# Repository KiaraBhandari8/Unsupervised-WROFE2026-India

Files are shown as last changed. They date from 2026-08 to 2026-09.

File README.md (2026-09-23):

# Unsupervised-WROFE2026-India

Official repository of Team Unsupervised for the World Robot Olympiad Future Engineers 2026. This project documents the design, development, and implementation of our autonomous vehicle, integrating computer vision, embedded systems, and real-time navigation algorithms to solve the Future Engineers challenge.

## Table of Contents

- [Unsupervised-WROFE2026-India](#unsupervised-wrofe2026-india)
  - [Table of Contents](#table-of-contents)
  - [Team](#team)
  - [About the Challenge](#about-the-challenge)
  - [Performance Videos](#performance-videos)
    - [Challenge 1](#challenge-1)
    - [Challenge 2](#challenge-2)
  - [List of Components](#list-of-components)
  - [Robot Pictures](#robot-pictures)
  - [Mobility Management](#mobility-management)
    - [Controlling the Motor](#controlling-the-motor)
    - [Robot Dimensions](#robot-dimensions)
    - [Drivetrain Torque Calculation](#drivetrain-torque-calculation)
  - [Building Instructions](#building-instructions)
  - [Power and Sense Management](#power-and-sense-management)
    - [Power Distribution](#main--power-supply)
    - [Robot Dimensions](#robot-dimensions)
    - [Controlling the Motors](#controlling-the-motors)
  - [Building Instructions](#building-instructions)
  - [Power & Sense Management](#power--sense-management)
    - [Hardware Architecture](#hardware-architecture)
      - [Current Stabilisation](#current-stabilisation)
  - [Obstacle Management](#obstacle-management)
    - [Vision Methods and Decision Making](#vision-methods-and-decision-making)
    - [1) Image Pipeline (Inputs Used by Algorithms)](#1-image-pipeline-inputs-used-by-algorithms)
    - [MATLAB-Based Obstacle Detection and Colour Segmentation](#matlab-based-obstacle-detection-and-colour-segmentation)
      - [HSV-Based Colour Segmentation](#hsv-based-colour-segmentation)
      - [Generation of Colour Masks](#generation-of-colour-masks)
      - [Obstacle Selection](#obstacle-selection)
      - [Engineering Significance](#engineering-significance)
    - [2) Wall Following Calculations](#2-wall-following-calculations)
    - [3) Obstacle Handling Calculations](#3-obstacle-handling-calculations)
    - [4) Corner Detection](#4-corner-detection)
    - [5) Crash Detection](#5-crash-detection)
    - [6) Arbitration: Choosing the Action](#6-arbitration-choosing-the-action)
    - [7) Tuning Notes](#7-tuning-notes)
    - [Block Diagrams](#block-diagrams)
      - [Open Round Block Diagrams](#open-round-block-diagrams)
      - [Obstacle Round Diagrams](#obstacle-round-diagrams)
      - [Corner Logic Open Round](#corner-logic-open-round)
      - [Corner Logic Obstacle Round](#corner-logic-obstacle-round)
    - [Possible Improvements](#possible-improvements)
    - [Thank You](#thank-you)

## Team
wro
 <br>

| Name | Profile | Role |
| --- | --- | --- |
| Kiara Bhandari | Grade 10 @ Oberoi International School | Team Member |
| Shubh Gupta | Grade 10 @ Chatrabhuj Narsee School | Team Member |
| Dhanak Seth | Grade 8 @ Vibgyor High School | Team Member |
| Vinay Ummadi | Mentor @ MakerWorks Lab | Team Mentor |

## About the Challenge

The World Robot Olympiad (WRO) is an international robotics competition that encourages students to develop problem-solving, programming, and engineering skills. The Future Engineers category is designed for students aged 14–22 years and focuses on autonomous driving. The challenge simulates real-world traffic conditions and requires teams to design and program a fully autonomous robot car.

The challenge requires students to construct an autonomous robot which will undergo 2 rounds. First, an open round challenge where the robot would need to complete 3 rounds around the arena within the time limit of 3 minutes (180 seconds). The second round, which is the obstacle round consists of navigating through red and green pillars, where the robot would move from the left of the green pillar and from right of the red pillar. The robot should once again, not exceed a time limit of 3 minutes.

## Performance Videos
### Challenge 1
[Open Challenge Video 1 - Practice before Nationals on Youtube](https://youtu.be/0ms9o5Httb8?si=1wx8qC69ZG0JPVR6)

### Challenge 2
[Obstacle Round Video 1 - Practice before Nationals on Youtube](https://youtu.be/hUuTf3fS2V0?si=C6_U4KdSrS-R3kdz) <br>
[Obstacle Round Video 2 - Practice before Nationals on Youtube](https://youtu.be/6QX_Y3WPMX4?si=ZPCf-lAfKMT5tgFE) <br>
[Obstacle Round Video 3 - Practice before APAC on Youtube](https://youtu.be/BjEGykfpRfE)

## Matlab Video
[Youtube Video: Explanation On How We Used Matlab](https://youtu.be/cSldkeClAug?si=Nf5bUmlcxWWf90j0)
[Obstacle Round Video 2 - Practice before Internationals on Youtube](https://youtu.be/6QX_Y3WPMX4?si=ZPCf-lAfKMT5tgFE)

## List of Components

| Name of Component | Quantity | Picture |
| ---- | ---- | ---- |
| Raspberry Pi 5 (Cooling Fan + SD Card) | 1 |  |
| Raspberry Pi Camera Module 3 Wide | 1 |  |
| ESP32 Development Board | 1 |  |
| YDLidar T-Mini Plus LiDAR | 1 |  |
| PCA9685 16-Channel PWM Servo Driver | 1 |  |
| TB6612FNG Dual Motor Driver | 1 |  |
| GY-87 10-DOF Multi-Sensor IMU Module | 1 |  |
| Silicon Labs CP2102 USB-to-UART Bridge | 1 |  |
| HC-SR04 Ultrasonic Sensor | 1 |  |
| MG996 Servo Motor | 1 |  |
| 12V DC 600 RPM Encoder Motor | 1 | 617ee66bbc025d72da6e6f25634cf3e0 image 1066x800 |
| LiPo 3s 11.1v 2200 mAh Battery | 1 |  |
| LM2596 Step-Down (Buck) DC-DC Switching Voltage Regulator Integrated Circuit (ESP32) | 1 |  |
| XY-3606 DC-DC Step-Down Buck Converter Module (Raspberry Pi) | 1 |  |
| RC Car Rear Differential | 1 |  |
| N20 wheels | 4 |  |
| Lazy Susan Turntable Bearings | 1 |  | 

[Why we chose each component](mech/components) <br>
## Robot Pictures

WhatsApp Video 2026-08-18 at 6 07 50 PM

360° view

<br> <br>

| Front View | Left View | Top View |
| --- | --- | --- |
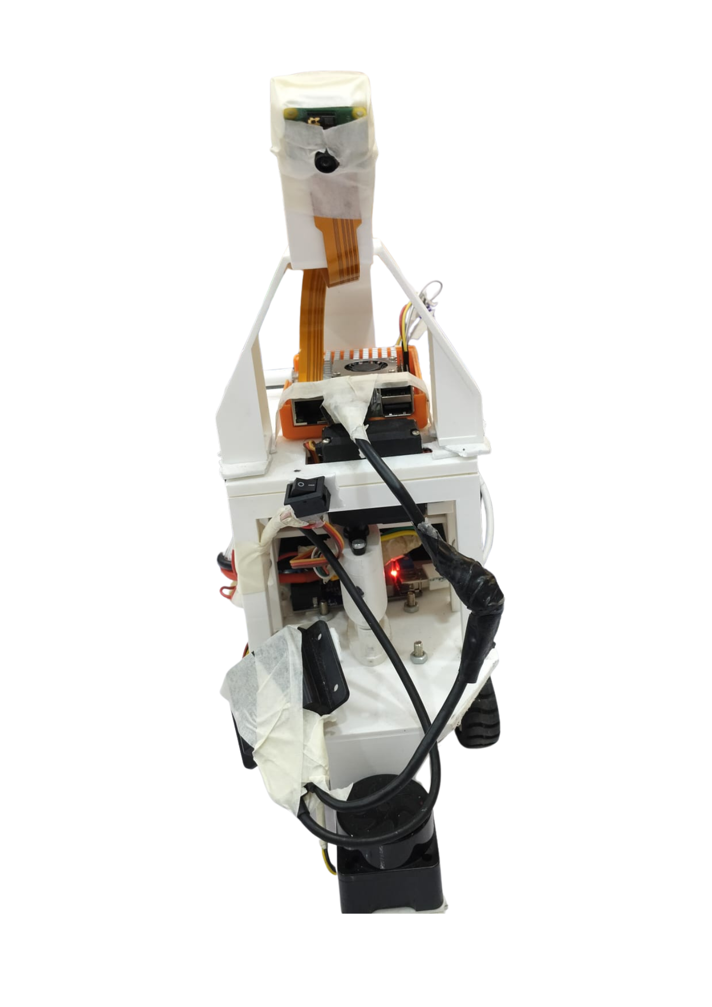
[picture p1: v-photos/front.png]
Front View
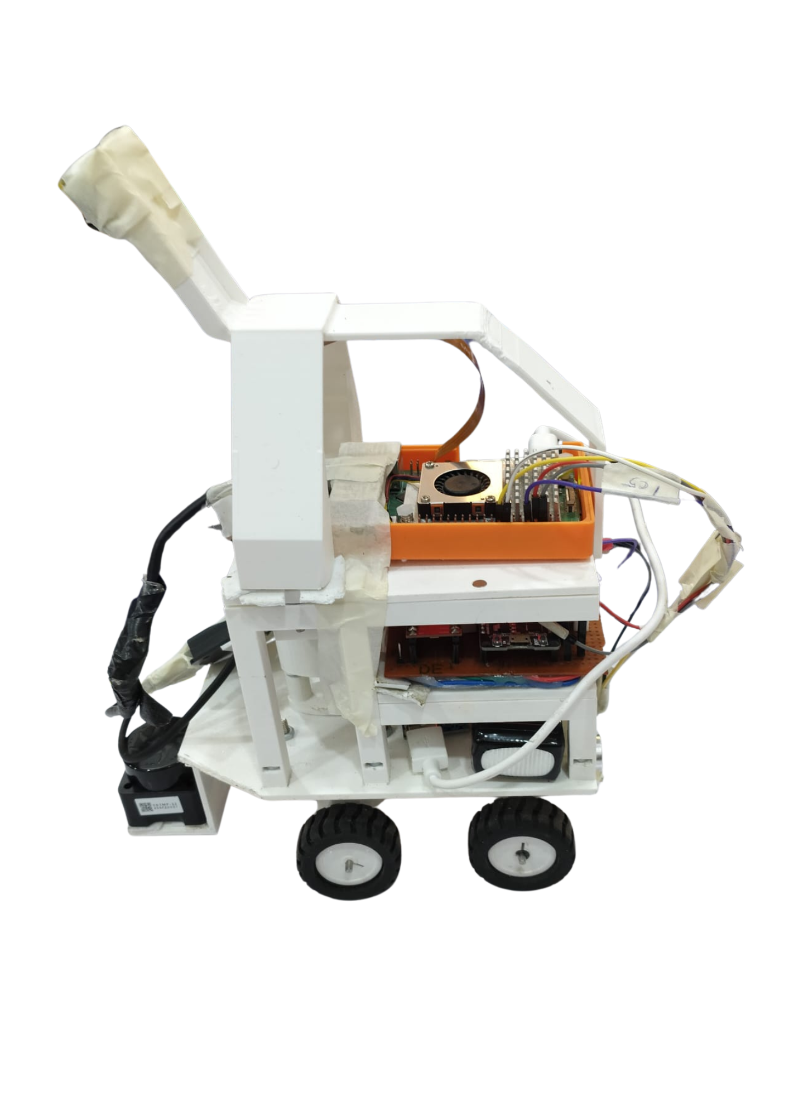
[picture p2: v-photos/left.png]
Left View
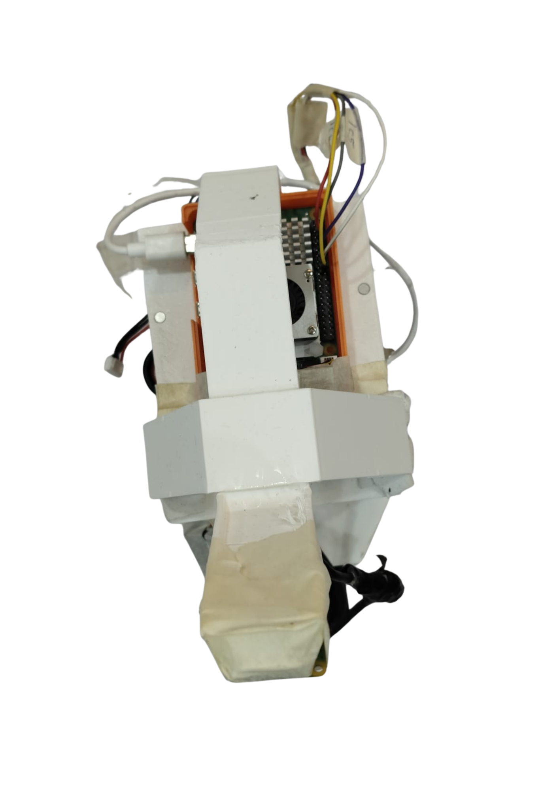
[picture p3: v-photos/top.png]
Top View
|  |  |  |

| Back View | Right View | Bottom View |
| --- | --- | --- |
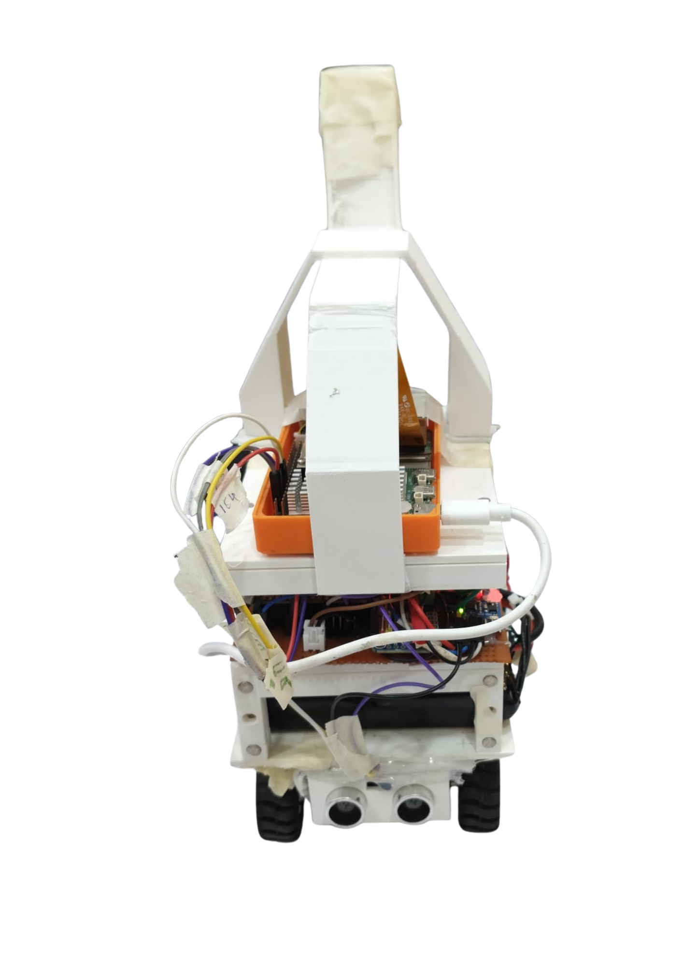
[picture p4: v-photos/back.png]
Back View
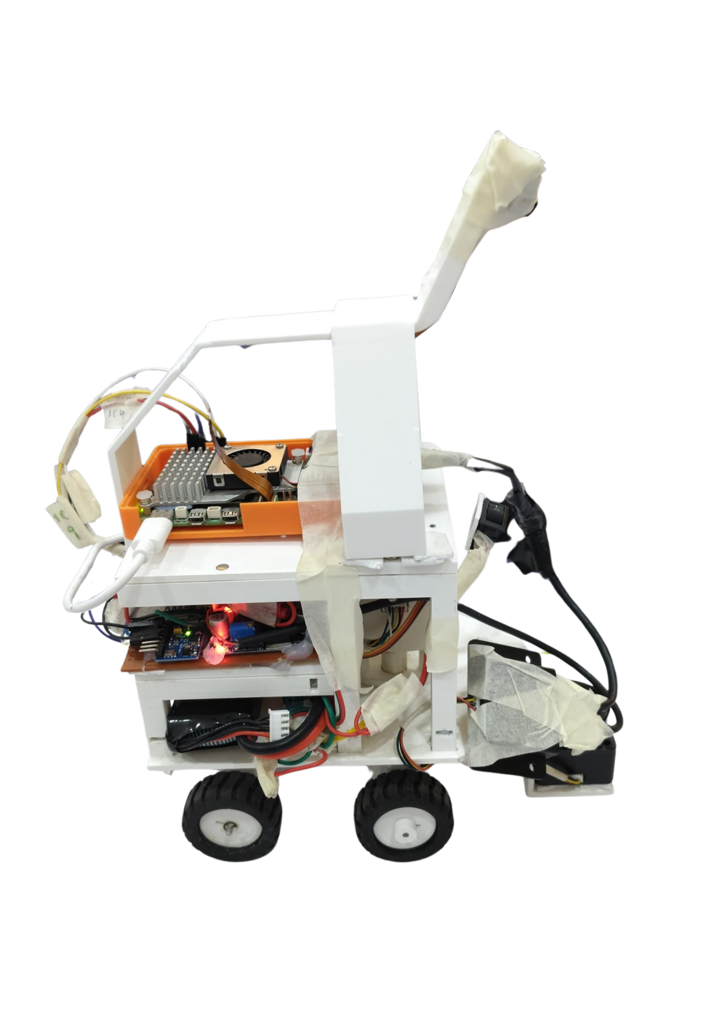
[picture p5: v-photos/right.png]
Right View
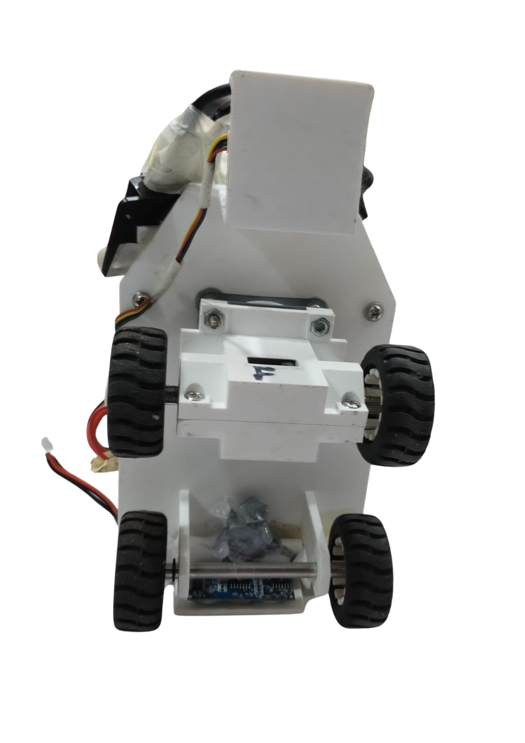
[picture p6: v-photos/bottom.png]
Bottom View
|  |  |  |

## Mobility Management

The robot uses a rear-wheel-drive system consisting of one 12V 600 RPM DC encoder motor connected to an RC car rear differential. The differential transfers the motors' motion to the rear wheels while allowing the wheels to rotate at different speeds during turns. Steering is provided by an MG996 servo motor connected to the front steering mechanism. The robot uses four N20 wheels, with the rear wheels being driven and the front wheels used for steering. A Lazy Susan turntable bearing supports the steering assembly.

WhatsApp Image 2026-08-18 at 6 07 51 PM

### Robot Dimensions

- **Dimensions:** **22 cm × 11 cm × 29 cm**  
**Length × Width × Height**

**Why We Chose These Dimensions:**

We chose the dimensions of **22 cm × 11 cm × 29 cm** to provide a balance between **stability, manoeuvrability, and component placement**. The 50 cm length provides enough space to accommodate the drivetrain, battery, electronics, and sensors while maintaining a compact overall design. The 29.5 cm width provides sufficient stability during movement and turning without making the robot unnecessarily wide. The 22 cm height keeps the robot's centre of mass relatively low while providing enough clearance for mounting the camera, LiDAR, and other electronic components. These dimensions also allow the robot to remain compact enough for efficient navigation around the track.

- **Custom Mounts**: Holders for servo, differential gear, camera, and LiDAR and more. <br> [CAD Designs](mech)

- **Differential Gear**: The differential  provides smoother and more mechanically appropriate turning behaviour than directly forcing both wheels to rotate at the same speed. <br> [Why We Chose Differential Gears](mech/components)

### Controlling the Motors

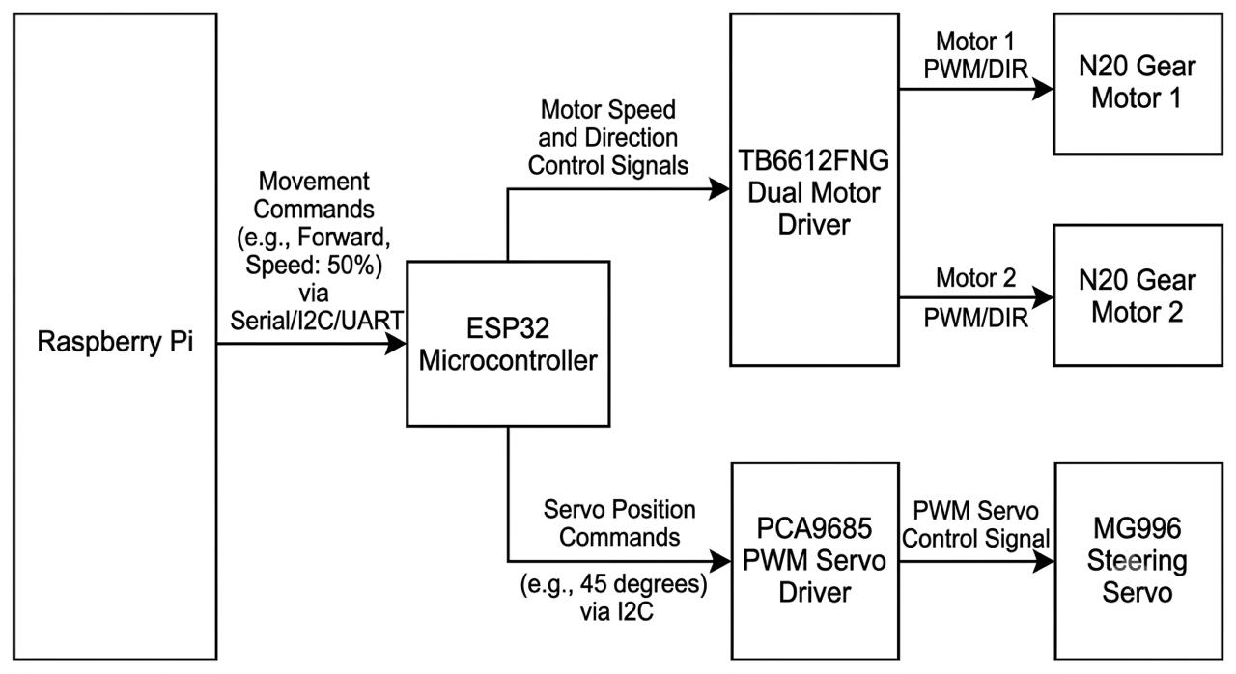
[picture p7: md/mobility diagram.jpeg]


The DC motor is controlled by the ESP32 through the TB6612FNG dual motor driver. The Raspberry Pi sends movement commands to the ESP32, which controls the motors according to the required speed and direction. The MG996 steering servo is controlled by the ESP32 through the PCA9685 PWM servo driver.

This code showcases our navigation manoeuvre. You can go through this to get a better understanding. [Click here for navigation code](codes/aug15_1/nav_process.py)

### Drivetrain Torque Calculation

[Click here to view the drivetrain torque calculation](docs/drivetrain-torque-calculation.md)

-------------------------------------------------------
## Building Instructions
- **Parts list** <br>
  Make sure you have all components ready before starting: 3D-printed parts, motors, drivers, electronics, screws, sensors and connectors. A complete detailed table with quantities, sources, link, prices and usage is included below for reference.<br>
[Click here to open the parts list](mech/components)

- **3D Printing Parts**<br>
  Using any 3D printer, start by 3D printing the necessary parts for the assembly. We used a Prusa Core 1. Every part needed has a STL file which you can use with any printer. If you're adventurous and want to modify a part, open the .STL file in your favorite CAD software. If you're unsure of what part you're printing, make sure to open the PNG file which contains a picture of the part.<br>
[Click here to open the .STL files](mech)

- **Custom PCB**<br>
  Fabricate the board using the Gerber files located in the project repository. Carefully solder all components onto the PCB, including power regulators, motor drivers, and pin headers. Before connecting battery power, perform a continuity test with a multimeter across the power and ground rails to ensure there are no short circuits.<br>
[Click here to open the schematics](elec/schematic.PNG)

- **Assemble the Robot**<br>
  Mechanically assembling the robot is quite straight-forward. The tricky part comes with the electrical connections. Make sure you follow correctly the following electrical drawings.<br>
_Take notes, the drawings are quite small ! Make sure to download the PDF files to be able to zoom._ <br>
[Click here to open the electrical drawings](elec/schematic.PNG)

- **Sensor Setup (LiDAR & Pi Camera)** <br>
  Secure the Pi Camera and LiDAR module onto their designated 3D-printed chassis mounts. Connect the camera to the host board's CSI port using the ribbon cable, ensuring correct pin orientation. Wire the LiDAR module to the host via USB or serial interface. Run the hardware verification scripts to verify the camera stream and confirm that 360-degree scan data is streaming cleanly into memory.<br>

## Power and Sense Management

### 1. Main Power Supply

The robot is powered from a single 11.1 V, 3S LiPo battery. A main power switch is placed immediately after the battery's positive terminal, so that every downstream circuit — both buck converters and the raw motor rail — is gated by this one switch. 

From the switched 11.1 V rail, power is distributed along two separate paths. The raw 11.1 V supply is routed directly to the VM pins of the TB6612FNG motor driver, so the motor is driven at full battery voltage without regulation. The same rail also feeds the input of the first buck converter, from which all regulated voltages in the system are ultimately derived.

This separation is intentional. Motor drive current is comparatively high and electrically noisy, due to switching transients and back-EMF, and is therefore kept on an unregulated path rather than passed through a converter that would otherwise have to absorb that noise.

### 2. Buck Converter 1: XY3036 (11.1 V to 5 V, 5 A)

The XY3036 steps the 11.1 V battery rail down to 5 V at up to 5 A. Its primary load is the Raspberry Pi 5, supplied through its USB-C input. The Pi 5 has comparatively high current demands, particularly with a camera and a USB-connected LiDAR adapter attached, and its power management IC actively monitors the current capability advertised on USB-C; an insufficient supply results in throttling. A 5 A-rated converter feeding the USB-C port directly is intended to avoid this condition.

The 5 V/5 A output of the XY3036 also serves as the input to the second buck converter, so every other regulated rail in the system is derived from this same supply, stepped down once more.

### 3. Buck Converter 2: LM2596 (5 V to 5 V, 2 A)

The LM2596 takes its input from the XY3036's 5 V output and regulates it down to 5 V at up to 2 A. Although the nominal voltage is unchanged, this stage is not redundant: its function is to provide a second, independently regulated rail so that the Raspberry Pi's supply is not shared directly with the motor driver logic or the servo driver.

The Raspberry Pi remains on the XY3036's dedicated rail. The ESP32 DEVKITC, the logic supply (VCC) of the TB6612FNG, and, indirectly, the BN0085 gyroscope and PCA9685 servo driver are instead supplied from the LM2596 rail. The motor driver's logic side switches at high frequency, and the servo draws current in bursts during motion; if these loads shared a rail directly with the Pi, the resulting ripple could couple into the Pi's supply and produce intermittent faults that are difficult to diagnose during competition. A second regulation stage isolates these load transients from the Pi's supply rail.

### 4. Rail Distribution Summary

| Rail Source | Load | |
| --- | --- | --- |
| 11.1 V (unregulated) | Battery, via main switch | TB6612FNG motor driver (VM) |
| 5 V, 5 A | XY3036 | Raspberry Pi 5 (USB-C) |
| 5 V, 2 A | LM2596, from XY3036 output | ESP32 DEVKITC, TB6612FNG logic (VCC) |
| 3.3 V | ESP32 onboard regulator, from LM2596 rail | BN0085 gyroscope, PCA9685 servo driver logic |

The 3.3 V rail is not produced by a discrete third converter. It is generated by the ESP32 DEVKITC's own onboard regulator, which takes its input from the LM2596 rail. The supply path to the gyroscope therefore passes through four regulation stages: battery, XY3036, LM2596, and the ESP32's internal regulator.

The PCA9685 has a separate supply pin, V+, in addition to its logic VCC, used specifically for the servo output stage. Servo current draw during motion is significantly higher than the I2C logic current, and keeping this path distinct from the logic supply reduces the likelihood of that current draw appearing as noise on the I2C bus.

### 5. Power Distribution to Sensing Elements

Each sensing subsystem draws power along a distinct path, generally following the controller to which it is connected.

The N20 encoders use a four-wire connection: two signal lines (C1 and C2, for quadrature pulse counting) to ESP32 GPIO32 and GPIO33, and separate VCC and GND lines supplying the encoder's Hall-effect sensing circuitry independently of the motor's own power pins. This separation prevents switching noise on the motor supply from affecting the encoder signal lines.

The ultrasonic sensor is supplied from a 5 V rail local to the Raspberry Pi, with TRIG and ECHO connected to Pi GPIO17 and GPIO27 respectively; it operates entirely within the Pi's I/O and power domain.

The LiDAR unit is powered through its USB adapter. Its VCC, GND, SCL, and SDA lines are local to the LiDAR module, and communication with the Raspberry Pi is carried over a USB cable via a USB translator, which also supplies the module's 5 V through the same cable. Its power is therefore drawn from the Pi's own USB supply rather than from either buck converter directly.

The Pi Camera 5 is powered over the CSI ribbon cable directly from the Raspberry Pi board.

The BN0085 gyroscope operates on the 3.3 V rail described in Section 4, with SDA and SCL connected to the ESP32 for orientation data.

In general, peripherals physically and logically associated with the Raspberry Pi (camera, ultrasonic sensor, LiDAR) draw power through the Pi's own supply, while peripherals associated with the ESP32 (encoder signal circuitry, gyroscope, servo driver) draw power through the ESP32's 5 V and 3.3 V rails. Power and data paths for each subsystem are therefore kept within the same controller domain.

### 6. Common Ground

All regulators, integrated circuits, and sensors share a common ground reference. This includes the UART bridge between the Raspberry Pi and the ESP32, which explicitly specifies a shared ground line alongside its TX and RX connections (Pi Pin 8 to ESP32 RX2, Pi Pin 10 to ESP32 TX2). UART is a single-ended signaling scheme with no differential reference, so a common ground between the two devices is required for reliable communication, independent of the condition of either device's own supply rail.

### 7. Summary

The power architecture reflects three design decisions. Motor power is kept unregulated and isolated from all logic rails. The Raspberry Pi is supplied from a dedicated high-current converter that is not shared as a load by any other device. All comparatively noisy loads, including motor driver logic, the servo, and the IMU, are supplied from a second, independently regulated converter, isolating their transients from the Pi's supply.

#### Current Stabilisation

The robot uses DC-DC buck converters to regulate the voltage supplied to its electronic components. This prevents the higher battery voltage from being supplied directly to components that require lower operating voltages.

The regulated power system helps maintain stable operation of the Raspberry Pi, ESP32, sensors, and control electronics during operation.

### Hardware Architecture

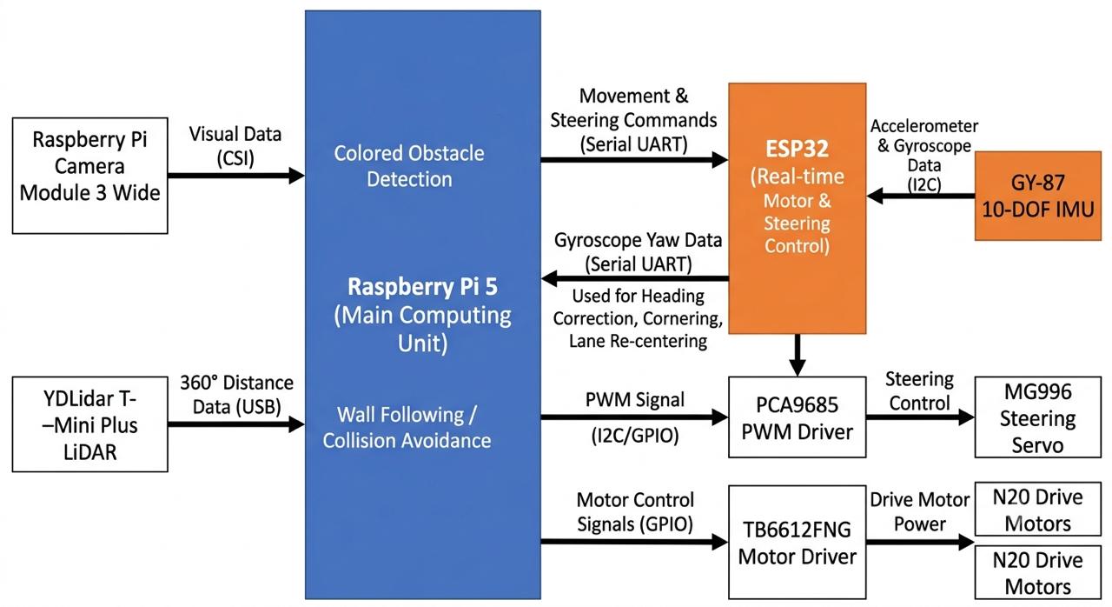
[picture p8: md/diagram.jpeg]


The Raspberry Pi 5 acts as the main computing unit and processes data from the Raspberry Pi Camera Module 3 Wide and YDLidar T-Mini Plus LiDAR. The Raspberry Pi communicates with the ESP32 through a serial connection to send movement and steering commands. <br> [Why We Chose the Pi 5](mech/components)

The ESP32 handles real-time motor and steering control and interfaces with the robot's sensors. The GY-87 10-DOF IMU provides accelerometer and gyroscope data to estimate the robot's orientation and heading. Gyroscope yaw data is streamed from the ESP32 to the Raspberry Pi and is used by the navigation software for heading correction, cornering, and lane re-centering after obstacle avoidance. <br> [Why We Chose the ESP32](mech/components)

The YDLidar T-Mini Plus provides distance measurements around the robot for wall following and collision avoidance, while the camera provides visual information for detecting and avoiding coloured obstacles. <br> [Why We Chose the YDLiDAR](mech/components)

The PCA9685 PWM driver controls the MG996 steering servo, while the TB6612FNG motor driver controls the DC motors. 

## Obstacle Management

The robot uses a combination of computer vision, LiDAR, and IMU data to detect obstacles and determine its path through the arena.

### Vision Methods and Decision Making

Untitled design

The Raspberry Pi Camera Module 3 Wide is used to identify the coloured obstacles in the arena. Image processing is used to detect red and green obstacles and determine their position relative to the robot.

The YDLidar T-Mini Plus provides distance measurements around the robot. These measurements are used for wall following, obstacle detection, and determining the available space around the robot.

The GY-87 IMU provides accelerometer and gyroscope data. Gyroscope yaw data is used by the navigation software for heading correction, cornering, and lane re-centering after obstacle avoidance.

The navigation system combines information from these sensors to determine the appropriate steering angle and motor speed. The Raspberry Pi processes the sensor data and sends movement commands to the ESP32, which controls the steering servo and drive motor. 

# Obstacle Detection, Processing, and Avoidance

## 1. System Overview

Two sensors split the job:

| Sensor | Role |
|---|---|
| Camera (RGB, HSV color analysis) | Figures out the **type** of obstacle — red pillar, green pillar, or none |
| LiDAR | Measures **distance** to walls and obstacles, spots corners, and handles wall-following and stop triggers |

In short: the camera tells the robot *what* it's looking at and which side to pass on; the LiDAR tells it *how close* things are and *when* to act. The driving logic combines both to decide on one maneuver per track section.

---

## 2. Detection Stage

### 2.1 Track Isolation (Track Segmentation)

Before checking for obstacle colors, the system figures out which part of the camera frame is actually the drivable mat, so background clutter or walls never get mistaken for an obstacle.

docuemntaiton1 <br> 

- Convert the frame from BGR to **HSV color space** and threshold the **L (lightness) channel** to separate bright mat pixels from dark background/obstacle pixels.
- Run a morphological **close** (dilate → erode) to bridge small gaps caused by colored tape lines, so tape doesn't split the mat into separate regions.
- Use `cv2.connectedComponentsWithStats` to find all bright regions, then keep only the one **touching the bottom row** of the frame — that's the track the robot is currently on. Discard everything else.
- This gives a binary **track mask** (255 = track, 0 = everything else). An obstacle sitting on the mat blocks the brightness underneath it, so it shows up as a dark "hole" inside the track region.
- Fill that hole in to get a **filled interior mask** — "everything inside the track boundary, obstacle or not." This is needed because the raw track mask would blank out the very obstacle the pipeline is trying to find; the filled version is what color detection actually gets restricted to.

### 2.2 Color-Based Pillar Detection

With the interior mask ready, the system looks for red and green pillars using HSV thresholding:

Screenshot 2026-09-19 at 6 23 32 PM <br>

- Convert BGR to **HSV**, since HSV separates color (hue) from lighting (saturation/value) much better than BGR.
- **Green mask:** one hue range (default 35–85) plus minimum saturation/value floors.
- **Red mask:** red wraps around the hue wheel at 0°/180°, so two hue ranges (default 0°–7° and 173°–180°) are combined with `cv2.bitwise_or`.
- Saturation/value floors are **tunable live** at runtime (thread-safe parameter store) to handle lighting changes at the venue without re-flashing code. Hue bounds stay mostly fixed since hue doesn't shift much with lighting — only their edges (where red/green fade into orange/yellow) are adjustable.
- Apply a **morphological close** (7×7 elliptical kernel) to each color mask first, to reconnect a single obstacle that glare or reflections split into separate blobs.
- **AND** both masks with the track interior mask from Section 2.1. This removes any pillar-colored object outside the track boundary at the pixel level, so it's never even offered to the contour detector.
- If a post-corner rejection zone is active (a short window after a corner maneuver where leftover motion or a partial-turn frame could cause false detections), also mask out a vertical strip on the relevant side.
- Detection is limited to a **Region of Interest (ROI)**: roughly the central 70% of frame width (15%–85%) and middle 76% of height (12%–88%). This avoids lens distortion and clutter at the extreme edges, while still leaving room for distant, small, high-in-frame obstacles to register at their true size.
- Run `cv2.findContours` separately on the red and green masks. Drop any contour under **900 px²** to filter out tape specks, reflections, or noise.
- If both colors have a surviving contour, pick the **larger** one, assuming the bigger blob is the nearer, currently-relevant obstacle.
- Output: a `logic_label` of `red_obstacle`, `obstacle` (green), or `none`.
- As a diagnostic aid: even if nothing clears the area filter, the largest unfiltered contour (either color) is still tracked and reported with its real area — this helps tell "obstacle present but too small/clipped" apart from "color threshold isn't catching it at all."

---

## 3. Processing Stage

There are two separate processing modes for two different purposes.

### 3.1 Continuous PD Steering Correction

Used for real-time, frame-by-frame pillar avoidance and for the standalone diagnostic tool:

Screenshot 2026-09-19 at 6 23 43 PM <br>

- **Target point:** each color aims for an x-coordinate at the ROI edge opposite the side it must pass on (green → right edge, red → left edge), so the correction steers toward the correct passing side, not just toward the obstacle.
- **Error:** horizontal pixel distance between the obstacle's detection point (bottom-center of its bounding box) and its target x-coordinate.
- **PD control law:**
  ```
  steering_angle = Kp * error + Kd * (error - previous_error)
  ```
  with `Kp = 0.45`, `Kd = 0.1`. The derivative term smooths out single noisy frames. `previous_error` is stored per color across frames so the derivative term has something to compare against.
- **Y-offset correction:** an extra term, `Y_OFFSET_GAIN * (obstacle_bottom_y - ROI_top_y)`, adds more steering push the closer the obstacle's bottom point is to the robot, applied in the direction of the x-error's sign. So correction strengthens as the robot approaches, instead of staying constant.
- **Fallback when nothing is detected:** switch to line-centering — compare black pixel area on the left vs. right half of the ROI (the track lines) and steer to balance them. If the frame is very dark overall (mean grayscale under 50), treat it as a wall/corner ahead and apply a fixed sharp turn instead.
- When no pillar is tracked in a frame, reset both colors' `previous_error` to zero, so a stale derivative doesn't cause a steering spike if a pillar reappears later.

### 3.2 Single-Shot Classification with Lap Memory

The competition run doesn't steer continuously around pillars — instead it takes **one classification read per checkpoint** via `read_obstacle()`:

Screenshot 2026-09-19 at 6 23 54 PM <br>

- **Lap 1:** every section is actively scouted — capture a frame, run it through the Section 2 pipeline, and store the result (`red` / `green` / `none`) in a section map keyed by `(direction, section, level)`. A section can hold up to three obstacle positions (L1/L2/L3), but only specific combos are valid (a single obstacle, or L1+L3 — never L1+L2 or L2+L3).
- **Later laps:** skip the camera for any section already scouted, and just recall the stored classification. This avoids risking a bad live read (motion blur, blocked view, lighting drift) for something that's already known and constant.
- If a scouting read got cut short (e.g. a safety timeout), `read_obstacle()` falls back to a live capture instead of trusting an incomplete record.

---

## 4. Avoidance Stage

Once a `logic_label` (live or recalled) is available, the robot runs a fixed, pre-defined maneuver rather than steering freely:

- **Green obstacle →** pass on the **right** (pillar stays on the robot's left).
- **Red obstacle →** pass on the **left** (pillar stays on the robot's right).
- **No obstacle →** take the default straight-through route.

Each maneuver typically pairs with LiDAR-driven **wall-following-and-stop** (Section 5): the robot advances under wall-follow PID until the LiDAR's front distance crosses a stop threshold (350 mm for both green and "none" at checkpoint L3), then the next scripted turn fires.

---

## 5. LiDAR's Role in Avoidance

While the camera identifies the obstacle, the LiDAR continuously provides the distance/geometry needed to execute the maneuver safely:

Screenshot 2026-09-19 at 6 24 36 PM <br>

- **Front distance:** average of valid LiDAR points within ±10° of straight ahead — the main trigger for "stop advancing, execute next turn."
- **Wall-parallel error:** PID input measuring how parallel the robot is to the wall it's following (left wall clockwise, right wall counter-clockwise, chosen dynamically from live shared state). Keeps a steady 500 mm standoff while passing a pillar.
- **Side-zone triggers:** points in the 50°–90° zone on each side are checked against a 200 mm threshold. 3+ such points trip a raw "obstruction on this side" flag — an independent safety signal separate from the wall-follow PID, for reacting faster than the PID alone might.
- **Corner detection:** a split-and-merge algorithm looks for an L-shaped discontinuity in the LiDAR data, signaling a real track corner (not a pillar). This is handled by a separate cornering routine.

---

## 6. End-to-End Flow

```mermaid
flowchart TD
    A[Camera frame captured] --> B[Track segmentation: isolate drivable mat]
    B --> C[Build filled interior mask]
    C --> D[HSV threshold: red mask and green mask]
    D --> E[Morphological close: bridge glare gaps]
    E --> F[Mask to track interior + ROI + reject zone]
    F --> G[Contour detection per color]
    G --> H[Filter contours below 900px minimum area]
    H --> I{Contour survives filter?}
    I -- No --> J[logic_label = none]
    I -- Yes --> K[Select larger of red/green contour]
    K --> L[logic_label = red_obstacle or obstacle]

    J --> M[Lap 1: record none in section map]
    L --> N[Lap 1: record color in section map]
    M --> O[Lap 2+: recall from section map, skip camera read]
    N --> O

    O --> P{Recorded classification}
    P -- Green --> Q[Execute pass-on-right route]
    P -- Red --> R[Execute pass-on-left route]
    P -- None --> S[Execute default straight route]

    T[LiDAR scan] --> U[Front distance]
    T --> V[Wall-parallel PID error]
    T --> W[Side-zone trigger]
    T --> X[Corner detection]

    U --> Y[Stop-and-turn trigger]
    V --> Z[Standoff distance during pass]

    Q --> Y
    R --> Y
    S --> Y
```

### MATLAB-Based Obstacle Detection and Colour Segmentation

[Youtube Video: Explanation On How We Used Matlab](https://youtu.be/cSldkeClAug?si=Nf5bUmlcxWWf90j0)
<br>

A key challenge in autonomous navigation is converting the visual information captured by the camera into information that the robot can use to make decisions. The raw camera image contains the complete environment, including the track, obstacles, boundaries and surrounding background. Processing this entire image directly would introduce unnecessary visual information and make reliable obstacle identification more difficult.

To address this, we developed a colour-based image-segmentation approach using MATLAB. MATLAB was used to analyse camera images and investigate how the coloured obstacles could be isolated from the surrounding environment. The segmentation process converts the original image into a simplified representation in which pixels corresponding to relevant obstacle colours are identified and separated from the background.

Screenshot 2026-09-06 at 8 28 53 PM

Our implementation uses the HSV colour space rather than directly thresholding the RGB image. HSV separates colour information into Hue, Saturation and Value components, allowing the colour characteristics of the obstacles to be analysed independently from the overall image representation.

The developed system specifically analyses the colour characteristics associated with the obstacles and generates separate segmentation masks for the detected colours. These masks are then filtered to remove insignificant regions before the remaining regions are used for obstacle identification.

The overall process can be represented as:

**Camera Image → RGB-to-HSV Conversion → Colour Thresholding → Binary Masks → Region Filtering → Obstacle Identification → Navigation Decision**

This process significantly reduces the complexity of the visual input available to the navigation system. Instead of processing every element of the camera image equally, the algorithm extracts the visual information that is directly relevant to obstacle detection.

MATLAB-based obstacle segmentation pipeline. The original camera image is converted into colour-specific segmentation masks. The red and green masks isolate pixels belonging to the corresponding obstacle colours, while the segmented overlay visualises the regions identified by the algorithm. The selected obstacle is subsequently highlighted for use in the navigation process.

**MATLAB obstacle-perception pipeline: raw image → colour segmentation → filtered candidate regions → obstacle identification** 

Copy of obstacle details

#### HSV-Based Colour Segmentation

The RGB camera image is converted into HSV representation before segmentation. This allows the algorithm to define thresholds using Hue, Saturation and Value rather than relying directly on the three RGB intensity channels.

For each target obstacle colour, a range of acceptable HSV values is defined. A pixel is classified as belonging to the target colour only when its HSV components fall within the specified ranges.

This can be represented conceptually as:

$$
H_{\min} \leq H(x,y) \leq H_{\max}
$$

$$
S_{\min} \leq S(x,y) \leq S_{\max}
$$

$$
V_{\min} \leq V(x,y) \leq V_{\max}
$$

Pixels satisfying these conditions are assigned to the corresponding binary mask.

An important implementation detail was the treatment of red. Because red lies around the boundary of the Hue scale, it cannot always be represented effectively using one continuous Hue interval. Therefore, the implementation uses two red Hue ranges, which are subsequently combined into a single red mask.

This prevents valid red pixels from being incorrectly excluded simply because they occur on opposite sides of the Hue representation boundary.

#### Generation of Colour Masks
Separate binary masks are generated for the detected obstacle colours. In the resulting masks, pixels satisfying the selected colour criteria are represented as foreground pixels, while pixels that do not satisfy the criteria are rejected.

The resulting masks provide a substantially simpler representation of the environment than the original camera image. For example, the red mask contains only the regions identified as red, while the green mask contains only the regions identified as green.

This separation allows subsequent processing to operate on specific candidate obstacle regions rather than the complete camera frame.

The segmentation output therefore acts as an interface between raw visual perception and geometric obstacle detection.

Screenshot 2026-09-08 at 8 03 03 PM

#### Obstacle Selection

Following segmentation and filtering, the detected regions can be evaluated as obstacle candidates. The visual overlay provides a direct representation of which region has been identified by the algorithm as the relevant obstacle.

In the demonstrated test image, the algorithm successfully isolates the coloured obstacle from the surrounding environment and identifies the corresponding region as the obstacle candidate.

This is an important transition in the perception pipeline: the algorithm moves from pixel-level classification to object-level interpretation.

In other words:

Pixel classification → Connected region → Obstacle candidate → Navigation information

This extracted information can then be provided to the navigation system to influence the robot's movement and obstacle-avoidance behaviour.

Screenshot 2026-09-08 at 8 04 24 PM

#### Engineering Significance

The MATLAB segmentation process allowed us to reduce a high-dimensional camera image into a smaller set of meaningful visual features. Instead of treating the entire image as equally important, the algorithm selectively extracts regions corresponding to potential obstacles.

This creates a structured perception pipeline in which colour information is converted into spatial information, and spatial information can subsequently be converted into navigation decisions.

The significance of the approach is therefore not simply that an obstacle can be visually highlighted. The segmentation provides the foundation for enabling the robot to interpret its environment computationally and make autonomous decisions based on the detected obstacles.

MATLAB was used for image-processing development, analysis and validation, while the resulting vision approach was integrated into the robot's deployed software architecture.

### 2) Wall Following Calculations

LiDAR measurements are used to determine the robot's distance from the walls.

The navigation algorithm compares the measured distance with the desired wall distance and calculates a steering correction. This allows the robot to maintain a suitable position within the lane while moving around the arena.

- Multi-Ray Sampling: Pulls depth readings from key positions in the scan array: straight left ($-90^\circ$), straight right ($+90^\circ$), and front diagonals ($\pm 45^\circ$).  
- Heading & Alignment: Calculates lateral offset by subtracting right distance from left distance, while diagonal rays determine the robot's tilt angle relative to parallel track walls.
- PD Control Loop: Feeds distance error ($P$) and rate of drift ($D$) into a Proportional-Derivative steering controller to keep the robot smoothly centered in the lane. <br>

Look at [Lidar_Process.py](codes/aug15_1/lidar_process.py) for more understanding

### 3) Obstacle Handling Calculations

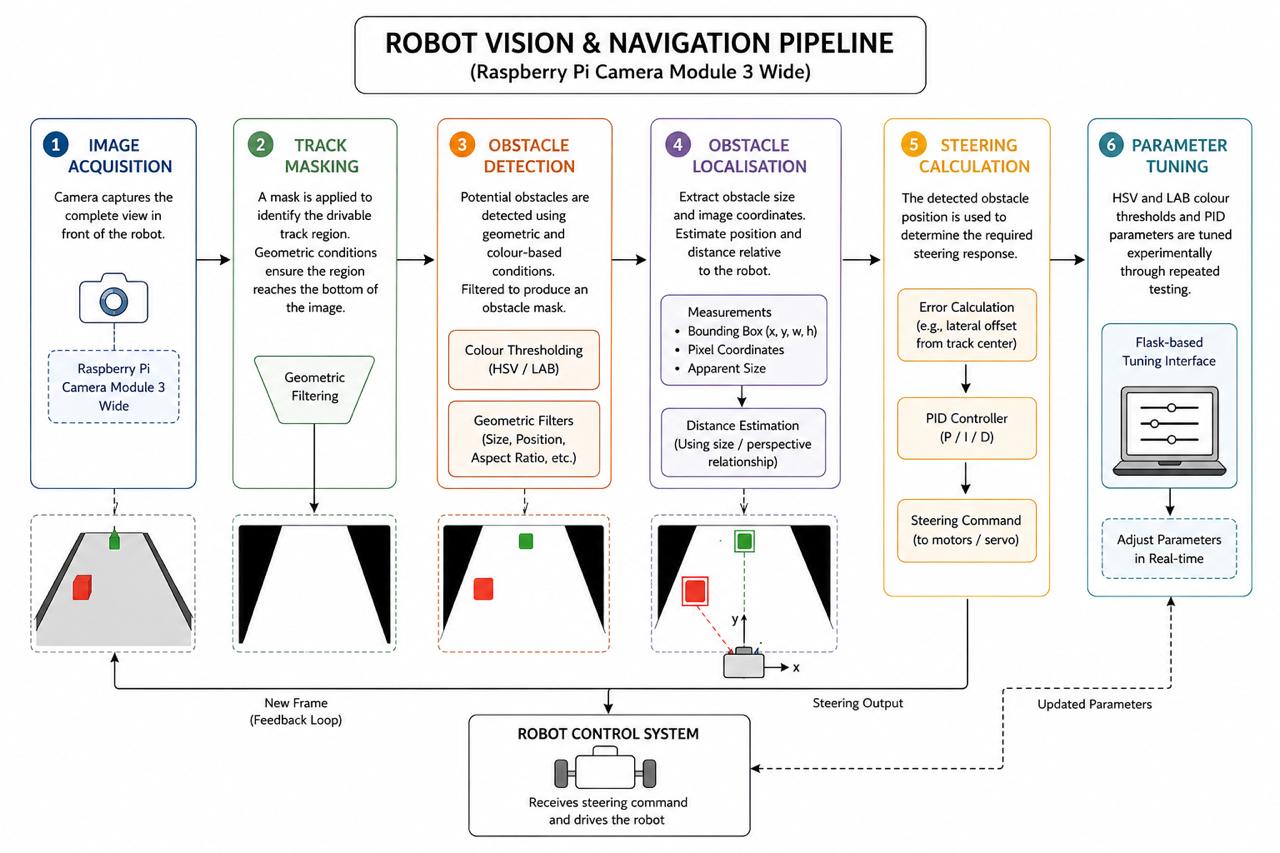
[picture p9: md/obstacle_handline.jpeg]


The robot uses the Raspberry Pi Camera Module 3 Wide to detect the track and coloured obstacles. The image-processing pipeline consists of several stages:

1. **Image acquisition:** The camera captures the complete view in front of the robot.

2. **Track masking:** A mask is applied to identify the drivable track region. Geometric conditions are used to filter the detected region, including requirements for the region to reach the bottom of the image. This helps identify the area of the track that is relevant to the robot's current position.

3. **Obstacle detection:** Potential obstacles are detected within the camera image using geometric and colour-based conditions. Conditions such as the obstacle's height, width, position, and relationship with the track are used to filter detections and produce an obstacle mask.

4. **Obstacle localisation:** Once an obstacle is detected, its size and image coordinates are extracted. These measurements are used to estimate its position and distance relative to the robot.

5. **Steering calculation:** The detected obstacle position is used to determine the required steering response. PID controllers are used to adjust the steering based on the calculated error.

6. **Parameter tuning:** HSV and LAB colour thresholds and PID parameters are tuned experimentally through repeated testing. The Flask-based tuning interface allows vision parameters to be adjusted during testing without repeatedly changing the main source code.

### 4) Corner Detection
- Pattern Recognition: Detects turn entry when diagonal depth rays suddenly spike outward (wall disappears) while front distance readings shrink.
- Snapshot Retrieval: Uses SharedScanReader to capture a frozen snapshot of the 361-slot distance array.
- Arc Execution: Suspends standard wall-following and hands steering authority to execute_cornering(), which runs a pre-calculated turning arc until side walls reappear.  

### 5) Crash Detection

The LiDAR is used to detect imminent collisions by monitoring the distance in the forward region of the robot. When an obstacle is detected within the defined safety threshold, collision avoidance is given priority over normal navigation.

The navigation system determines an escape direction based on the available space and temporarily overrides the normal steering behaviour to avoid the collision.

- Proximity Guard: Scans a $30^\circ$ forward wedge (indices $-15^\circ$ to $+15^\circ$) in the scan buffer, triggering an emergency stop if any value drops below $0.12\text{m}$.
- Stall Guard: Monitors wheel encoder tick rates against motor throttle commands. Flags a crash if throttle is active but wheel rotation halts for over 200ms.
- Emergency Intervention: Instantly overrides all routines to cut forward throttle, trigger reverse power, and steer away from the obstacle.

### 6) Arbitration: Choosing the Action

ChatGPT Image Aug 22, 2026 at 11_03_22 AM

The navigation system uses a priority-based arbitration system to determine which behaviour should control the robot at any given moment. Higher-priority behaviours override lower-priority behaviours when multiple conditions are detected simultaneously.

The behaviour hierarchy is:

**Imminent collision avoidance**: Highest priority. If a collision is detected as imminent by the LiDAR, the robot immediately performs an escape manoeuvre.

**Corner turning**: A committed corner-turning manoeuvre takes priority over normal obstacle avoidance and wall following. It is interrupted only by an imminent collision.

**Side obstacle avoidance**: LiDAR side-proximity warnings override camera-based pillar avoidance when the robot is too close to a side wall.

**Camera obstacle avoidance**: Red and green obstacles detected using computer vision generate a steering response.

**LiDAR wall following**: When no higher-priority behaviour is active, the robot follows the wall using LiDAR measurements and PID control.

**Fallback**: If none of the above behaviours can provide a valid navigation command, the robot continues straight at the cruise speed.

This hierarchy prevents conflicting behaviours from simultaneously controlling the steering system and ensures that immediate safety conditions take precedence over normal navigation.

### 7) Tuning Notes

The steering and navigation parameters are tuned through repeated testing on the arena. Parameters such as steering corrections, motor speed, wall-following distance, and obstacle detection thresholds are adjusted to improve stability and reduce unnecessary corrections. Colour parameters for obstacles can be tuned using an HSV adjuster on a Flask interface while the robot is running.

### Block Diagrams
#### Open Round Block Diagrams
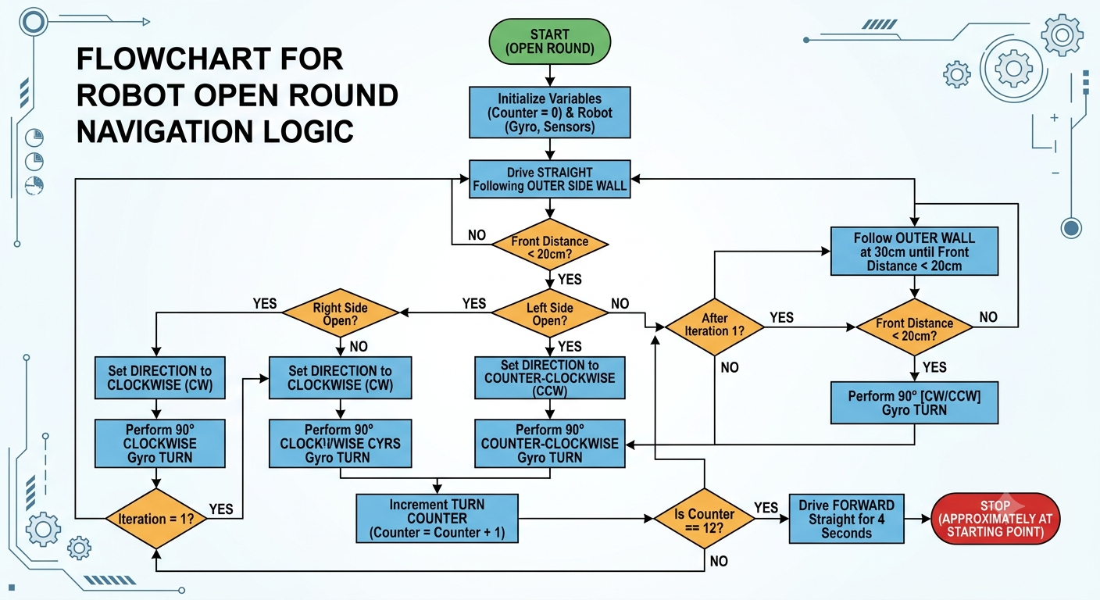
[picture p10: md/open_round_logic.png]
Open Round Logic


#### Obstacle Round Diagrams
```mermaid
%%{init: {'theme': 'base', 'themeVariables': {'lineColor': '#333333'}, 'flowchart': {'nodeSpacing': 25, 'rankSpacing': 35, 'curve': 'linear'}}}%%
flowchart TD
    CAM[Camera Frame] --> L1
    LID[LiDAR Scan] --> LF
    LID --> LS
    LID --> LC

    subgraph VISION["Vision Pipeline (Sections 4-6)"]
        L1["Layer 1: Track Segmentation<br/>LAB-L threshold -> largest bottom-touching blob"]
        L1 --> IM["Interior Mask<br/>(fills obstacle holes back in)"]
        IM --> L2["Layer 2: HSV Color Gating<br/>red/green thresholds + morph close"]
        L2 --> G1["Gate 1: Track interior mask"]
        G1 --> G2["Gate 2: Post-corner reject strip"]
        G2 --> G3["Gate 3: ROI (15-85% w, 12-88% h)"]
        G3 --> CF{"Contour >= 900px?"}
        CF -->|Yes| AVOID["PD Steering (Kp .45/Kd .10)<br/>+ Proximity Y-offset"]
        CF -->|No| FALLBACK["Line-centering fallback<br/>or corner-avoid"]
    end

    subgraph LIDARP["LiDAR Pipeline (Sections 7-8)"]
        LF{"Front +/-5deg<br/>< 150mm?"}
        LF -->|Yes| STOP["EMERGENCY STOP"]
        LF -->|No| LS{"Side zone 50-90deg<br/>3+ pts < 200mm?"}
        LS -->|"3-frame confirm"| SIDEAVOID["Side avoidance<br/>10-25deg, scaled"]
        LS -->|"No / 4-frame clear"| WALLFOLLOW["Wall-following<br/>30% dist / 70% align"]
        LC{"Corner detected?"}
    end

    subgraph CORNER["Cornering (Section 9)"]
        LC -->|Yes| APPROACH["Approach: align to wall<br/>until front < 350mm"]
        APPROACH --> LANE{"Fresh read<br/>> 500mm?"}
        LANE -->|Yes| ARC["Lane 1: wide arc"]
        LANE -->|No| PIVOT["Lane 2/3: in-place pivot"]
        ARC --> BACK
        PIVOT --> BACK["Backward maneuver<br/>PID wall-hold"]
        BACK --> USTOP{"Rear <= 200mm<br/>x3?"}
        USTOP -->|"Yes / 4s timeout"| DONE["Corner complete"]
    end

    subgraph PARKOUT["Parking-Out (Section 10)"]
        SNAP["Side-obstacle<br/>color snapshot"] --> DECIDE["CW/CCW + color<br/>-> distance + turn"]
        DECIDE --> NEAR["150mm"]
        DECIDE --> FAR["550mm"]
        DECIDE --> NONE["500mm"]
    end

    AVOID --> SUPPRESS["Suppress same-side LiDAR<br/>trigger 1.0s (Section 11)"]
    SIDEAVOID --> SHARED
    WALLFOLLOW --> SHARED
    SUPPRESS --> SHARED["Shared Robot State"]
    FALLBACK --> SHARED
    STOP --> SHARED
    DONE --> SHARED

    SHARED --> NAV["Nav Process<br/>State Machine (Section 12)"]
    NAV --> CMD["ESP32 -> Motor + Servo"]

    classDef vision fill:#cfe2f3,stroke:#1155cc,stroke-width:1.5px,color:#000
    classDef lidar fill:#f9d4ec,stroke:#a64d99,stroke-width:1.5px,color:#000
    classDef corner fill:#e6d5f5,stroke:#674ea7,stroke-width:1.5px,color:#000
    classDef parking fill:#d0ece7,stroke:#0e6655,stroke-width:1.5px,color:#000
    classDef danger fill:#f4cccc,stroke:#cc0000,stroke-width:1.5px,color:#000
    classDef safe fill:#d9ead3,stroke:#38761d,stroke-width:1.5px,color:#000
    classDef fusion fill:#e2e2e2,stroke:#555555,stroke-width:1.5px,color:#000

    class L1,IM,L2,G1,G2,G3,CF,AVOID,FALLBACK vision
    class LF,LS,LC lidar
    class APPROACH,LANE,ARC,PIVOT,BACK,USTOP,DONE corner
    class SNAP,DECIDE,NEAR,FAR,NONE parking
    class STOP danger
    class WALLFOLLOW,SIDEAVOID safe
    class SHARED,NAV,CMD,SUPPRESS fusion

    style VISION fill:#eaf2fb,stroke:#1155cc,stroke-width:1.5px
    style LIDARP fill:#fdf1f8,stroke:#a64d99,stroke-width:1.5px
    style CORNER fill:#f4edfb,stroke:#674ea7,stroke-width:1.5px
    style PARKOUT fill:#e9f6f3,stroke:#0e6655,stroke-width:1.5px

    linkStyle default stroke:#333333,stroke-width:1.6px
```

#### Corner Logic Open Round
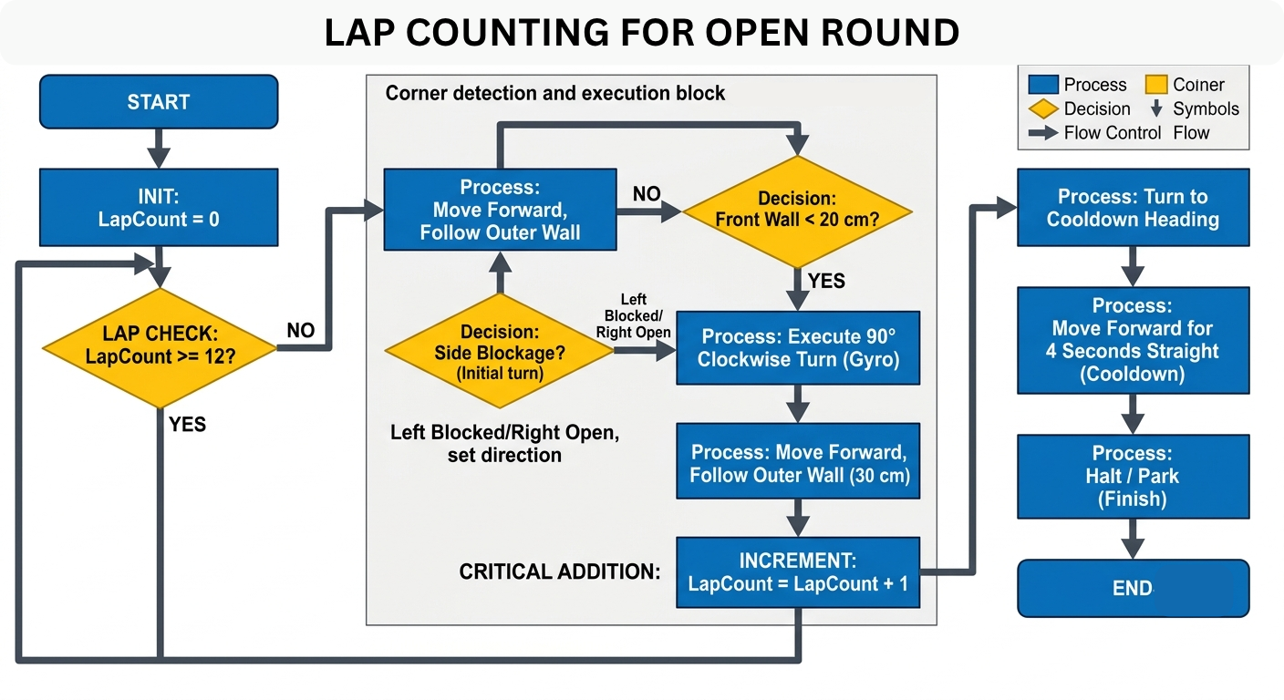
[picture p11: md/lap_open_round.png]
Open Round Lap Count Logic


#### Round Counting Obstacle Round

```mermaid
flowchart LR
    A([Start]) --> B["Lap 1: SCOUTING<br/>camera reads & saves to memory<br/>Drives sections 1-4"]
    B --> C["Laps 2 & 3: REPLAY<br/>camera off, drives from memory<br/>Drives sections 1-4 each lap"]
    C --> D(["Stop after lap 3,<br/>section 4"])

    A2([If PARKING_OUT armed]) --> B2["Before lap 1: LiDAR decides direction.<br/>Lap 1 Section 1 is replaced by the<br/>parking-out routine, then rejoins<br/>the normal flow at Section 2"]
    B2 -.-> B
```

**How the round counting works**

The robot's course is divided into 4 fixed "sections" (roughly corner-to-corner segments), and a full run is 3 laps around that same course — so 12 sections total, tracked with two simple counters: `current_lap` (1–3) and `current_section` (1–4).

- **Lap 1 is the "scouting" lap.** The camera is on, and as the robot drives each section it identifies obstacles and writes what it saw into memory (keyed by lap/section).
- **Laps 2 and 3 are "replay" laps.** The camera turns off, and the robot just drives off what it already memorized in lap 1 — same course, so no need to re-observe it.
- **The section counter drives the inner loop**, cycling 1→2→3→4 within each lap before the lap counter increments.
- **The run doesn't stop because a counter rolls over** — it stops because of one explicit check: "is this lap 3 *and* section 4?" (i.e., the very last section of the very last lap). When that's true, the robot just stops in place instead of continuing on to a section 5 that doesn't exist. Every other section transition automatically sets up and moves into the next one.

-------------------------------------------------------
### Possible Improvements
**1. Structural Reinforcement & Vibration Isolation**

- Material Upgrade: Switch high-stress 3D-printed parts from standard PLA to PETG, ABS, or Carbon-Fiber PETG to stop chassis flex during sharp, high-speed maneuvers.

- Vibration Dampening: Add TPU shock mounts or rubber grommets under the camera and LiDAR mounts. High-frequency motor vibrations introduce sensor noise into LiDAR distance scans and cause micro-blur in camera frames.

**2. Hardware Acceleration for the Vision Pipeline**

- Offloaded Processing: Move HSV color thresholding and contour tracking from the host CPU to a dedicated hardware accelerator (such as OpenCV GPU acceleration or a light Edge AI accelerator).

- Latency Reduction: Cuts camera processing latency from ~30ms down to under 5ms. This allows the obstacle detection algorithm to feed target updates into shared memory significantly faster, enabling higher safe cruising speeds.
-------------------------------------------------------
### Thank You

On behalf of Team Unsupervised, we want to extend our deepest gratitude to everyone who made this journey possible. A massive thank you to our incredible mentors — Vinay Sir, Vamsi Sir, and Abhay Sir — for your endless patience, technical guidance and for constantly pushing us to solve problems even when our code or hardware refused to cooperate. We are immensely grateful to the whole team at Makerworks Lab for giving us the space, tools, and encouraging environment to experiment, iterate, and bring our ideas to life. Finally, a special thank you to our parents, whose constant encouragement, belief in us, and behind-the-scenes support kept us going through every long hour. We truly couldn't have built any of this without your guidance, trust, and support!

WhatsApp Image 2026-08-25 at 00 44 52

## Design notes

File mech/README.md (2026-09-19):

# Mechanical Design Approach 

## 1. Basic Mechanical Choices

##### 1.1 Wheel Choice 
We chose the 43mm N20-compatible rubber wheels because they provide a good balance between grip, stability, manoeuvrability and size. The rubber tyre gives the robot good traction on the surface, reducing slipping and allowing more consistent movement and turning. The 43mm diameter is large enough to provide adequate ground clearance and smooth movement, while still being compact enough to fit within our robot’s design without taking up excessive space. Their 18mm width provides sufficient contact with the surface for stability without adding unnecessary weight. At only 18g per wheel, they help keep the robot lightweight, while their 3kg loading capacity provides more than enough support for our robot. The wheels are also directly compatible with N20 gear motors and have a 3mm shaft hole, simplifying the mechanical assembly. Additionally, the 12-pulse-per-revolution encoder provides accurate wheel rotation feedback, which can help with precise movement and distance control.

WhatsApp Image 2026-08-22 at 11 32 25

##### 1.2 Steering System 
- Prototype:
- Servo: 

##### 1.3 Differential Gear (Rear Wheels)
We chose an RC car rear differential gear to efficiently transfer power from the motor to both rear wheels while allowing the wheels to rotate at different speeds during turns. This is important because the outer wheel travels a greater distance than the inner wheel when the robot turns. The differential therefore reduces wheel slipping and friction, allowing smoother and more controlled turns.

differential gear

In our design, we changed the orientation of the differential gear to improve its efficiency and integration with the rest of the drivetrain. We also increased the distance between the LiDAR stand and the differential gear compared to last year’s design. Previously, the smaller spacing caused the differential assembly to come too close to the LiDAR stand, creating a risk of interference or collision. Increasing this clearance gives the LiDAR more space and prevents mechanical components from obstructing its operation.

This modification also makes the overall drivetrain more reliable by reducing unnecessary contact between components and providing better separation between the sensing and drive systems. The differential gear therefore contributes to both the robot’s turning performance and the improved mechanical layout of the final design.

##### 1.4 Dimension Choices 
**Dimensions:** **22 cm × 11 cm × 29 cm**  
**Length × Width × Height**

**Why We Chose These Dimensions:**

We chose the dimensions of **22 cm × 11 cm × 29 cm** to provide a balance between **stability, manoeuvrability, and component placement**. The 22 cm length provides enough space to accommodate the drivetrain, battery, electronics, and sensors while maintaining a compact overall design. The 11 cm width provides sufficient stability during movement and turning without making the robot unnecessarily wide. The 29 cm height keeps the robot's centre of mass relatively low while providing enough clearance for mounting the camera, LiDAR, and other electronic components. These dimensions also allow the robot to remain compact enough for efficient navigation around the track.

##### 1.6 LiDAR positioning
**Why We Placed the LiDAR at the Bottom Front of the Robot**

We decided to mount the LiDAR sensor as low as possible on the robot, and at the front, instead of putting it higher up or in the middle. Here's why we made that choice:

1. **The Boundaries Are Only 10 cm High**
The walls around the competition field are just 10 cm tall. If we mounted the LiDAR any higher than that, its scanning beam would pass over the top of the boundaries instead of hitting them. That would mean the robot couldn't "see" the walls at all, or it would only catch them at a weird angle that gives unreliable readings. By keeping the LiDAR low, close to the height of the boundaries, we make sure the sensor always detects them properly.

2. **We Only Use the Front, Left, and Right Readings**
Since the LiDAR is mounted at the front of the robot, we only look at the distance readings coming from three directions: straight ahead, to the left, and to the right. We don't use the readings from behind the robot, because that direction would just be pointing back into the robot's own body, not out into the field. This also means the robot doesn't have to process a full circle of data — just the three directions it actually needs to make driving decisions.

3. **It Keeps the Robot's Weight Low**
The LiDAR and the bracket that holds it are some of the heavier parts on the robot. By mounting them near the bottom, we keep the robot's center of gravity low. This makes the robot more stable when it's turning quickly, speeding up, or slowing down, so it's less likely to tip over during sharp movements.

4. **It Avoids Getting Blocked by the Robot's Own Parts**
If the LiDAR were mounted higher up, other parts of the robot — like motors, wires, or arms — could get in the way of its scanning beam. This would create blind spots or cause the sensor to pick up false readings from bouncing off the robot's own body. Mounting it low and at the front keeps its view clear.

5. **It Shortens the Wiring**
Since the LiDAR is near the bottom, close to where the main control board usually sits, the wires connecting them don't have to travel far. This means less clutter, less chance of signal problems, and it's easier to fix things if something goes wrong.

6. **It Protects the LiDAR from Getting Bumped**
Mounting the LiDAR low and tucked in helps protect its spinning parts from accidentally getting hit by other moving parts of the robot, like an arm or lift, which are usually mounted higher up and move around during a run.

7. **It Makes Combining Sensor Data Easier**
Our robot doesn't rely on the LiDAR alone — it also uses data from wheel encoders and an IMU (a sensor that tracks movement and orientation) to figure out where it is. When the LiDAR is mounted low and facing forward, it's easier to combine all this data together accurately, because everything is aligned in a similar reference point close to the ground.

---

```mermaid
flowchart TD
    A[Field boundaries are only 10 cm high] --> B[LiDAR mounted low and at the front]
    B --> C[Scans line up correctly with boundaries and obstacles]
    B --> D[Only Front, Left, and Right readings are used]
    D --> E[No need to check behind the robot]
    D --> F[Less data to process]
    B --> G[Keeps heavy LiDAR weight low]
    G --> H[Lower center of gravity]
    H --> I[More stable during fast turns]
    B --> J[Sensor view stays clear of motors, wires, and arms]
    J --> K[No blind spots or false readings]
    B --> L[Shorter wiring to the control board]
    L --> M[Less clutter and easier to fix]
    B --> N[LiDAR is protected from bumps]
    N --> O[Arms and lifts move above it without hitting it]
    B --> P[Easier to combine with IMU and encoder data]
    P --> Q[More accurate positioning overall]
```

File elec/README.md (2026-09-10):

# WRO Competition Robot – Complete System Documentation

A full breakdown of the electrical, sensor, and control architecture for the WRO Future Engineers competition robot.

---

## Table of Contents

1. [Main Power System](#1-main-power-system)
2. [Raspberry Pi 5](#2-raspberry-pi-5)
3. [Raspberry Pi ↔ ESP32 UART Communication](#3-raspberry-pi--esp32-uart-communication)
4. [ESP32 Controller](#4-esp32-controller)
5. [N20 Motor and Encoder](#5-n20-motor-and-encoder)
6. [N20 Encoder](#6-n20-encoder)
7. [BN0085 Gyroscope / IMU](#7-bn0085-gyroscope--imu)
8. [PCA9685 Servo Driver](#8-pca9685-servo-driver)
9. [MG996R Steering Servo](#9-mg996r-steering-servo)
10. [I²C Bus](#10-i²c-bus)
11. [LiDAR System](#11-lidar-system)
12. [Ultrasonic Sensor](#12-ultrasonic-sensor)
13. [Ground System](#13-ground-system)
14. [Overall Robot Architecture](#14-overall-robot-architecture)
15. [Control Cycle During a Run](#15-how-everything-works-together-during-a-run)

---

## 1. Main Power System

The robot is powered by an **11.1 V LiPo battery**.

### Power Flow

\`\`\`
11.1 V LiPo Battery
        │
        ▼
   Main Power Switch
        │
        ├──────────────► XY3036 Buck Converter
        │                    │
        │                    └── 5 V / 5 A
        │
        └──────────────► LM2596 Buck Converter
                             │
                             └── 5 V / 2 A
\`\`\`

The key design point in this version of the schematic: **both buck converters receive their input directly from the switched 11.1 V battery rail.** They are parallel power-conversion branches — not one converter feeding the other.

### XY3036

Converts **11.1 V → 5 V / up to 5 A**.

This high-current 5 V supply is used primarily for the **Raspberry Pi 5**, which can draw significantly more current than the smaller electronics.

### LM2596

Independently converts **11.1 V → 5 V / up to 2 A**.

Provides a separate 5 V rail for the lower-power electronics and peripherals.

### Why Two Converters?

Separates the power demands of the Pi from the rest of the electronics:

| Component | Supply |
|---|---|
| Pi 5 | High-current 5 V (XY3036) |
| ESP32 | 5 V input |
| Sensors | 5 V / 3.3 V rails |
| Servo system | 5 V supply |
| Other peripherals | 5 V supply |

All grounds are connected to a common ground reference.

> **Important:** The schematic should clearly show the two converters' inputs as parallel from the 11.1 V rail. Their 5 V outputs should **not** be tied together unless the converters are specifically designed for parallel operation.

---

## 2. Raspberry Pi 5

The Raspberry Pi 5 acts as the robot's high-level computer, handling:

- Camera processing
- Computer vision
- Obstacle detection
- LiDAR processing
- Navigation decisions
- Communication with the ESP32

Power: receives 5 V from the **XY3036** output.

### Camera

The **Pi Camera 5 Wide Angle** connects via the **CSI ribbon cable**, enabling computer-vision tasks such as identifying:

- Red pillars
- Green pillars
- Track/arena features
- Other visual navigation information

---

## 3. Raspberry Pi ↔ ESP32 UART Communication

\`\`\`
Pi Pin 8  TX ─────────► ESP32 RX2
Pi Pin 10 RX ◄───────── ESP32 TX2
Pi GND     ──────────── ESP32 GND
\`\`\`

Two-way communication link:

- **Pi → ESP32:** commands like `SET_SPEED`, `STEER_LEFT`, `STEER_RIGHT`, `STOP`
- **ESP32 → Pi:** encoder speed, motor position, IMU data, status information

**Division of responsibility:**

| Processor | Role |
|---|---|
| Raspberry Pi | High-level intelligence — "Where should the robot go?" |
| ESP32 | Low-level hardware control — "How do I make the motors and steering do that?" |

---

## 4. ESP32 Controller

The **ESP32 DevKitC** is the real-time hardware controller, interfacing with:

- N20 motor
- Encoder
- TB6612FNG
- BN0085 IMU
- PCA9685
- Steering servo

Supplied from the 5 V rail; its onboard regulator steps this down to 3.3 V for the ESP32's logic circuitry.

---

## 5. N20 Motor and Encoder

The robot uses an **N20 600 RPM motor** for propulsion, connected to the **TB6612FNG** motor driver (not directly to the ESP32). The driver supplies motor current while the ESP32 provides control signals.

### TB6612FNG Motor Driver

- **Motor power:** from the main battery rail (the N20 needs more voltage/current than logic electronics provide)
- **Control signals from ESP32:** `AIN1`, `AIN2`, `PWMA` — controlling forward/reverse direction and PWM speed

\`\`\`
ESP32
 │
 ├── AIN1 ──┐
 ├── AIN2 ──┤──► TB6612FNG ───► N20 Motor
 └── PWMA ──┘
\`\`\`

PWM allows the ESP32 to control motor speed.

---

## 6. N20 Encoder

Four encoder connections:

| Pin | Wire Color |
|---|---|
| C1 | Green |
| C2 | Yellow |
| VCC | Black |
| GND | Blue |

The two signal channels (C1/C2) connect to ESP32 GPIOs, providing rotational feedback. Because there are two channels, the ESP32 can determine both **speed** and **direction** of rotation via quadrature decoding — enabling closed-loop control.

Instead of simply commanding "run the motor at 60% PWM," the controller can target "maintain the required wheel speed" — useful for consistent WRO runs.

---

## 7. BN0085 Gyroscope / IMU

The previous **MPU6050** has been replaced by the **BN0085**.

\`\`\`
BN0085
 ├── VCC  → ESP32 3.3 V
 ├── GND  → GND
 ├── SDA  → ESP32 GPIO4
 ├── SCL  → ESP32 I²C clock
 └── PS0  → ESP32 3.3 V
\`\`\`

- **SDA:** BN0085 SDA → ESP32 GPIO4 (GPIO4 is the data line for this interface)
- **VCC:** 3.3 V from the ESP32 3V3 pin
- **PS0:** tied to 3.3 V, configuring the sensor's interface/address mode

### Why the IMU?

Gives the robot an additional orientation source alongside LiDAR. If the robot drifts (e.g., rotates slightly clockwise when it should go straight), the IMU detects the yaw change and the controller compensates via steering or motor control.

---

## 8. PCA9685 Servo Driver

Controls the steering servo via **I²C** from the ESP32.

\`\`\`
ESP32
   │
   │ I²C
   ▼
PCA9685
   │
   │ PWM
   ▼
MG996R Steering Servo
\`\`\`

The PCA9685 generates the PWM signal for the servo, handling it independently from the ESP32's main program loop.

---

## 9. MG996R Steering Servo

Controls the robot's front-wheel steering. Receives power, ground, and a PWM control signal; the ESP32 determines the desired steering angle.

\`\`\`
ESP32 command
     │
     ▼
PCA9685
     │
     ▼
MG996R
     │
     ▼
Front-wheel steering
\`\`\`

---

## 10. I²C Bus

Two primary signals:

- **SDA** – Data
- **SCL** – Clock

Multiple compatible devices can share the bus if addresses and electrical requirements align — in this architecture, this can include the **BN0085** and **PCA9685**.

> **Note:** Since the BN0085's SDA is moved to GPIO4, it should be treated as a separate ESP32 interface if GPIO4 isn't part of the same I²C bus configuration as the PCA9685.

---

## 11. LiDAR System

\`\`\`
LiDAR
   │
  USB
   ▼
USB Translator / USB Adapter
   │
  USB
   ▼
Raspberry Pi 5
\`\`\`

Provides distance measurements around the arena:

\`\`\`
            Front
               0°
               ↑
       -90° ◄ ROBOT ► +90°
        Left          Right
\`\`\`

Enables determination of:

- Distance to walls
- Position relative to boundaries
- Front obstacle distance
- Corner geometry
- Available space
- Pillar locations

Especially useful for the **WRO Future Engineers** navigation system.

---

## 12. Ultrasonic Sensor

**HC-SR04** ultrasonic sensor with four connections: `VCC`, `GND`, `TRIG`, `ECHO`.

| Signal | Pi Pin |
|---|---|
| TRIG | GPIO17 |
| ECHO | GPIO27 |

Provides a complementary distance measurement directly in front of the robot, alongside LiDAR.

---

## 13. Ground System

A shared electrical reference is essential:

\`\`\`
Battery GND
     │
     ├── Buck converters
     ├── ESP32
     ├── TB6612FNG
     ├── PCA9685
     ├── BN0085
     ├── Raspberry Pi
     ├── Ultrasonic sensor
     └── Other electronics
\`\`\`

Without a common ground, signals such as UART, I²C, PWM, and encoder feedback may not have a reliable reference.

---

## 14. Overall Robot Architecture

The robot can be viewed as three layers:

\`\`\`
                ┌──────────────────────────┐
                │      RASPBERRY PI 5      │
                │                          │
                │ Camera                   │
                │ LiDAR                    │
                │ Navigation               │
                │ Computer Vision          │
                │ High-level Decisions     │
                └────────────┬─────────────┘
                             │
                           UART
                             │
                             ▼
                ┌──────────────────────────┐
                │          ESP32           │
                │                          │
                │ Motor Control            │
                │ Encoder Feedback         │
                │ BN0085 IMU               │
                │ Steering Control         │
                └───────┬─────────┬────────┘
                        │         │
                   PWM/Direction  │ I²C
                        │         │
                        ▼         ▼
                   TB6612FNG   PCA9685
                        │         │
                        ▼         ▼
                   N20 Motor   MG996R
\`\`\`

Sensor data flow:

\`\`\`
Camera ──────────► Raspberry Pi
LiDAR ───────────► Raspberry Pi
Ultrasonic ──────► Raspberry Pi
                       │
                       │ UART
                       ▼
                     ESP32
                       ▲
                       │
                  BN0085 IMU
                       │
                  Encoder feedback
\`\`\`

---

## 15. How Everything Works Together During a Run

A typical control cycle:

1. **Sense** — The robot collects data from the camera, LiDAR, ultrasonic sensor, encoder, and BN0085.
2. **Process** —
   - *Raspberry Pi:* camera detections, LiDAR geometry, obstacle position, wall position
   - *ESP32:* encoder measurements, IMU measurements, low-level motor/servo control
3. **Decide** — The Pi determines an action, e.g., "steer slightly left" or "a green pillar is ahead, avoidance maneuver required."
4. **Communicate** — The Pi sends the command to the ESP32 over UART.
5. **Actuate** — The ESP32 changes steering angle via the PCA9685 and adjusts motor PWM via the TB6612FNG.
6. **Feedback** — The encoder and BN0085 provide continuous feedback, allowing the controller to correct the robot's motion in real time.

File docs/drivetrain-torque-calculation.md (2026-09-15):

# Drivetrain Torque and Driving Force Calculation

## 1. Objective

The purpose of this calculation is to determine the **drivetrain torque and driving force** of the WRO robot and to verify whether the two N20 gear motors provide sufficient torque for the robot's mass and wheel size.

The robot uses:

- 2 × N20 200 RPM gear motors
- 42 mm diameter wheels
- RC car rear differential
- 1.3 kg total robot mass
- 11.1 V, 2200 mAh 3S LiPo battery

The fundamental relationship between torque and tangential force is:

$$
\tau = F \times r
$$

where:

- $\tau$ = torque in N·m
- $F$ = tangential force in N
- $r$ = wheel radius in m

---

## 2. Given Parameters

| Parameter | Symbol | Value |
|---|---:|---:|
| Number of motors | $n$ | 2 |
| Motor speed | $N$ | 200 RPM |
| Rated torque per motor | $\tau_m$ | 0.52 kg·cm |
| Robot mass | $m$ | 1.3 kg |
| Wheel diameter | $D$ | 42 mm |
| Wheel radius | $r$ | 21 mm |
| Estimated drivetrain efficiency | $\eta$ | 85% |
| Gravitational acceleration | $g$ | 9.81 m/s² |

---

# 3. Calculate the Wheel Radius

The wheel diameter is:

$$
D = 42\text{ mm}
$$

The radius is half of the diameter:

$$
r = \frac{D}{2}
$$

$$
r = \frac{42}{2} = 21\text{ mm}
$$

Convert millimetres to metres:

$$
r = \frac{21}{1000}
$$

Therefore:

$$
\boxed{r = 0.021\text{ m}}
$$

The wheel radius used for the torque calculations is therefore:

$$
\boxed{0.021\text{ m}}
$$

---

# 4. Convert Motor Torque to N·m

The rated torque of one N20 motor is assumed to be:

$$
\tau_m = 0.52\text{ kg·cm}
$$

The conversion factor is:

$$
1\text{ kg·cm} = 0.0980665\text{ N·m}
$$

Therefore:

$$
\tau_m = 0.52 \times 0.0980665
$$

$$
\tau_m = 0.05099\text{ N·m}
$$

Therefore, the rated torque of **one motor** is:

$$
\boxed{\tau_m \approx 0.051\text{ N·m}}
$$

---

# 5. Calculate Total Motor Torque

The robot uses two N20 motors.

Assuming both motors contribute equally to the drivetrain:

$$
\tau_{total} = \tau_1 + \tau_2
$$

Since:

$$
\tau_1 = \tau_2 = 0.051\text{ N·m}
$$

we obtain:

$$
\tau_{total} = 0.051 + 0.051
$$

$$
\boxed{\tau_{total} = 0.102\text{ N·m}}
$$

Thus, the combined rated torque supplied by the two motors is:

$$
\boxed{0.102\text{ N·m}}
$$

before mechanical losses.

---

# 6. Account for Drivetrain Efficiency

The motors do not transfer 100% of their torque to the wheels.

Torque can be lost through:

- Motor gearbox
- Rear differential
- Bearings
- Axle
- Gear mesh
- Wheel connections

Assuming an overall mechanical efficiency of:

$$
\eta = 85\% = 0.85
$$

the effective wheel torque is:

$$
\tau_{wheel} = \tau_{total} \times \eta
$$

Substituting:

$$
\tau_{wheel} = 0.102 \times 0.85
$$

$$
\boxed{\tau_{wheel} = 0.0867\text{ N·m}}
$$

Therefore, the estimated torque actually available at the wheels is:

$$
\boxed{\tau_{wheel} \approx 0.087\text{ N·m}}
$$

---

# 7. Calculate the Driving Force

The torque at the wheels produces a tangential force at the contact point between the wheels and the ground.

Starting with:

$$
\tau = F \times r
$$

Rearranging:

$$
F = \frac{\tau}{r}
$$

Using:

$$
\tau = 0.0867\text{ N·m}
$$

and:

$$
r = 0.021\text{ m}
$$

we get:

$$
F = \frac{0.0867}{0.021}
$$

Therefore:

$$
\boxed{F \approx 4.13\text{ N}}
$$

The estimated total driving force is:

$$
\boxed{F_{drive} \approx 4.13\text{ N}}
$$

---

# 8. Calculate the Robot's Weight

The robot mass is:

$$
m = 1.3\text{ kg}
$$

Weight is calculated using:

$$
W = mg
$$

Therefore:

$$
W = 1.3 \times 9.81
$$

$$
\boxed{W = 12.75\text{ N}}
$$

The robot therefore exerts approximately **12.75 N** of downward force due to gravity.

---

# 9. Estimate Theoretical Acceleration

Using Newton's second law:

$$
F = ma
$$

Rearranging:

$$
a = \frac{F}{m}
$$

Using the estimated driving force:

$$
F = 4.13\text{ N}
$$

and:

$$
m = 1.3\text{ kg}
$$

we obtain:

$$
a = \frac{4.13}{1.3}
$$

$$
\boxed{a \approx 3.18\text{ m/s}^2}
$$

This is the **idealized motor-limited acceleration**.

In real operation, the acceleration will be lower because:

- Motor torque decreases as motor speed increases
- Tyre traction limits may occur
- Battery voltage drops under load
- Rolling resistance is present
- Mechanical losses vary with load
- The motor torque specification may represent stall or rated conditions rather than the torque available at 200 RPM

---

# 10. Calculate Theoretical Maximum Speed

The wheel diameter is:

$$
D = 0.042\text{ m}
$$

The circumference of the wheel is:

$$
C = \pi D
$$

Therefore:

$$
C = \pi(0.042)
$$

$$
\boxed{C \approx 0.132\text{ m}}
$$

The motors rotate at approximately:

$$
200\text{ RPM}
$$

Therefore, the theoretical linear velocity is:

$$
v = \frac{C \times RPM}{60}
$$

Substituting:

$$
v = \frac{0.132 \times 200}{60}
$$

$$
\boxed{v \approx 0.440\text{ m/s}}
$$

Converting to km/h:

$$
0.440 \times 3.6
$$

$$
\boxed{v \approx 1.58\text{ km/h}}
$$

Therefore, the theoretical no-load speed is approximately:

$$
\boxed{1.58\text{ km/h}}
$$

> **Important:** This is the theoretical no-load speed. The actual robot speed will normally be lower under load.

---

# 11. Check the Traction Limit

Torque alone does not determine how much force the robot can actually apply.

The tyres must be able to transfer the driving force to the WRO surface without slipping.

The maximum traction force can be estimated using:

$$
F_{traction} = \mu N
$$

where:

- $\mu$ = coefficient of friction between tyre and surface
- $N$ = normal force on the driven wheels

For example, if approximately **60% of the robot's weight** is supported by the rear driven wheels:

$$
N = 0.60 \times 12.75
$$

$$
N = 7.65\text{ N}
$$

If an example coefficient of friction is assumed:

$$
\mu = 0.8
$$

then:

$$
F_{traction} = 0.8 \times 7.65
$$

$$
\boxed{F_{traction} \approx 6.12\text{ N}}
$$

Our estimated driving force is:

$$
F_{drive} = 4.13\text{ N}
$$

Since:

$$
4.13 < 6.12
$$

the motor's estimated driving force would be below this example traction limit.

Therefore, under these assumptions, **motor torque is more likely to be the limiting factor than tyre traction during normal acceleration**.

> **Note:** The friction coefficient and rear weight distribution used here are estimates. They should not be presented as measured traction values.

---

# 12. Torque Distribution Through the Differential

The robot uses an **RC car rear differential**.

The two motors provide the combined input torque:

$$
\tau_{input} \approx 0.102\text{ N·m}
$$

After estimated drivetrain losses:

$$
\tau_{wheel} \approx 0.087\text{ N·m}
$$

During straight-line motion, the differential approximately distributes the available torque between the two rear wheels.

Assuming an equal torque distribution:

$$
\tau_{each\ wheel} = \frac{0.0867}{2}
$$

$$
\boxed{\tau_{each\ wheel} \approx 0.0434\text{ N·m}}
$$

The corresponding force per driven wheel is:

$$
F_{each} = \frac{0.0434}{0.021}
$$

$$
\boxed{F_{each} \approx 2.07\text{ N}}
$$

Therefore:

$$
2.07 + 2.07 \approx 4.14\text{ N}
$$

which agrees with the total driving-force calculation.

---

# 13. Summary of Calculated Values

| Quantity | Calculation | Result |
|---|---|---:|
| Wheel radius | $42/2$ | **21 mm** |
| Wheel radius | $21/1000$ | **0.021 m** |
| Torque per motor | $0.52 \times 0.0980665$ | **0.051 N·m** |
| Torque of 2 motors | $0.051 \times 2$ | **0.102 N·m** |
| Effective wheel torque | $0.102 \times 0.85$ | **0.087 N·m** |
| Driving force | $0.087/0.021$ | **4.13 N** |
| Robot weight | $1.3 \times 9.81$ | **12.75 N** |
| Idealized acceleration | $4.13/1.3$ | **3.18 m/s²** |
| Wheel circumference | $\pi \times 0.042$ | **0.132 m** |
| Theoretical speed | $0.132 \times 200/60$ | **0.440 m/s** |
| Theoretical speed | $0.440 \times 3.6$ | **1.58 km/h** |

---

# 14. Final Conclusion

> ### Drivetrain Torque Calculation
>
> The robot uses two N20 200 RPM geared motors to drive the rear axle through an RC car differential. The robot has a total mass of approximately **1.3 kg** and uses **42 mm diameter wheels**, giving a wheel radius of **0.021 m**.
>
> Assuming a rated motor torque of **0.52 kg·cm (0.051 N·m)** per motor, the combined rated motor torque is approximately **0.102 N·m**.
>
> Considering an estimated drivetrain efficiency of **85%**, approximately **0.087 N·m** of torque is available at the wheels.
>
> Using the wheel radius, this corresponds to an estimated theoretical driving force of approximately **4.13 N**.
>
> The theoretical wheel speed at 200 RPM is approximately **0.44 m/s (1.58 km/h)**.
>
> These calculations indicate that the drivetrain provides sufficient torque for the **1.3 kg robot under normal flat-surface operation**. However, actual performance will depend on tyre traction, battery voltage, motor loading, mechanical losses, and the exact torque-speed characteristics of the N20 motors.
>
> The calculated acceleration of **3.18 m/s²** should be treated as an idealized estimate rather than a measured value, since the motor's available torque changes with speed and load.

---

## 15. Important Engineering Considerations

The above calculations are useful for documenting the drivetrain design, but several values are based on assumptions.

### Motor Torque

The **0.52 kg·cm** value should be verified against the exact N20 motor datasheet or supplier specification. N20 motors are available with different gear ratios, voltages, speeds, and torque ratings.

### Drivetrain Efficiency

The assumed **85% efficiency** is an estimate. Actual efficiency depends on:

- Differential losses
- Bearing friction
- Gear alignment
- Axle friction
- Wheel friction
- Motor gearbox efficiency

### Battery Voltage

The theoretical calculations assume the motor operates close to its specified voltage. A 3S LiPo battery can have a significantly different voltage between full charge and discharge, which affects motor speed and torque.

### Real-World Speed

The calculated **1.58 km/h** is based on the nominal 200 RPM motor speed and 42 mm wheels. It is a theoretical value and does not account for load-dependent motor speed.

### Real-World Acceleration

The calculated **3.18 m/s²** should not be interpreted as the expected acceleration throughout the entire speed range. DC gear motors generally produce their highest torque at low speed, while available torque decreases as rotational speed increases.

---

## 16. Engineering Result

Based on the assumed motor specifications and drivetrain efficiency:

| Parameter | Result |
|---|---:|
| Total motor torque | **0.102 N·m** |
| Estimated wheel torque | **0.087 N·m** |
| Estimated driving force | **4.13 N** |
| Robot weight | **12.75 N** |
| Idealized acceleration | **3.18 m/s²** |
| Theoretical maximum speed | **0.440 m/s** |
| Theoretical maximum speed | **1.58 km/h** |

**Overall conclusion:** The calculated drivetrain torque is adequate for moving the 1.3 kg WRO robot on a flat competition surface under the stated assumptions. Further testing should be performed to determine the actual acceleration, maximum speed, traction limit, and drivetrain efficiency of the completed robot.

---

# Interactive Torque Calculator

The following interactive calculator allows the drivetrain parameters
to be changed dynamically.

### Parameters

- Motor torque
- Number of motors
- Wheel diameter
- Drivetrain efficiency
- Motor RPM

The calculator dynamically updates:

- Total motor torque
- Effective wheel torque
- Driving force
- Theoretical speed
- Torque-to-force visualisation

---

## Launch Calculator

🎛️ **[Open the Interactive Torque Calculator →](https://kiarabhandari8.github.io/Unsupervised-WROFE2026-India/docs/torque-calculator.html)**

> The calculator is hosted using GitHub Pages and runs directly in the browser.
$$

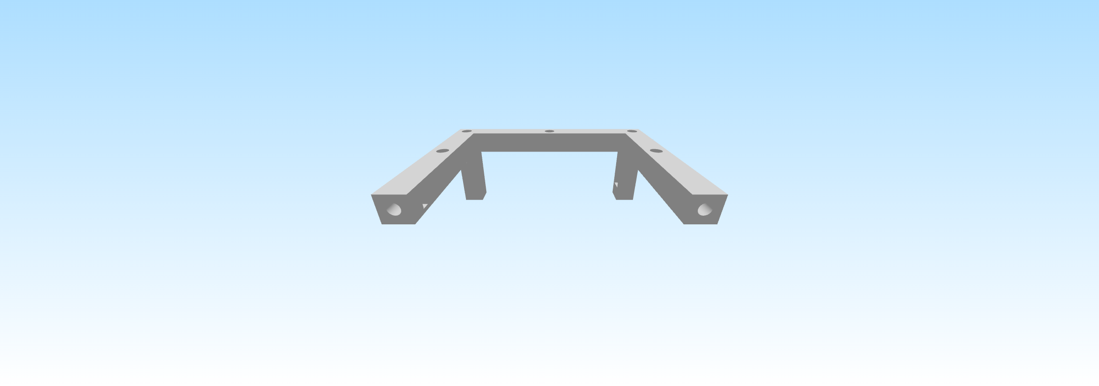
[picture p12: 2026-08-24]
mech/CAD designs/ImageToStl.com_Main Frame Back.jpg

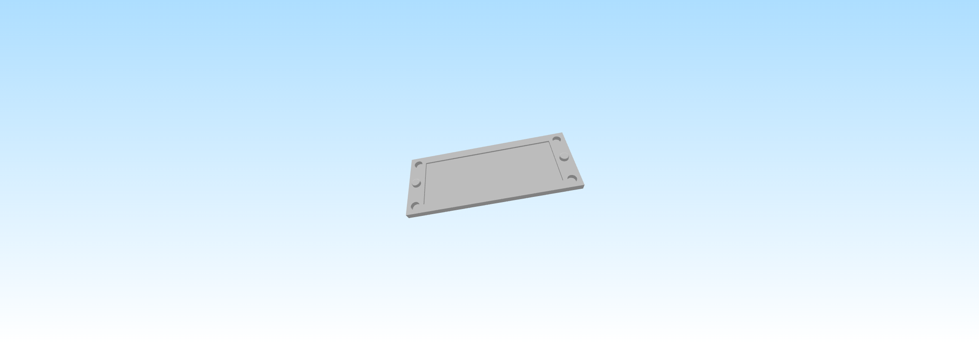
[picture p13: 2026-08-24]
mech/CAD designs/ImageToStl.com_Back Plate.jpg

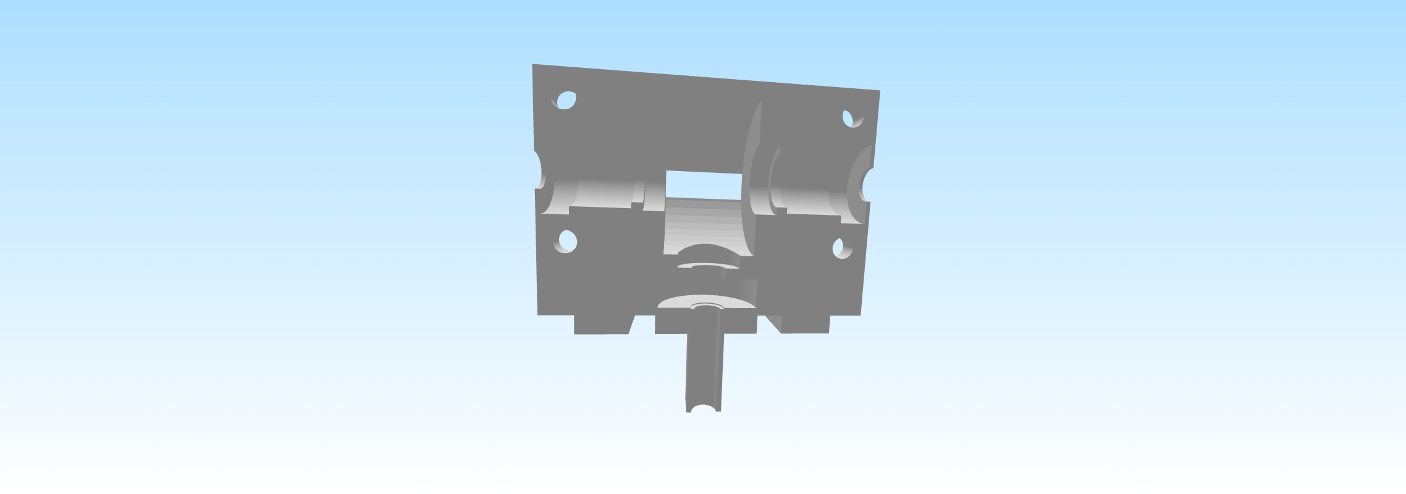
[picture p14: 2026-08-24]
mech/CAD designs/ImageToStl.com_Diffrential Part A.jpg

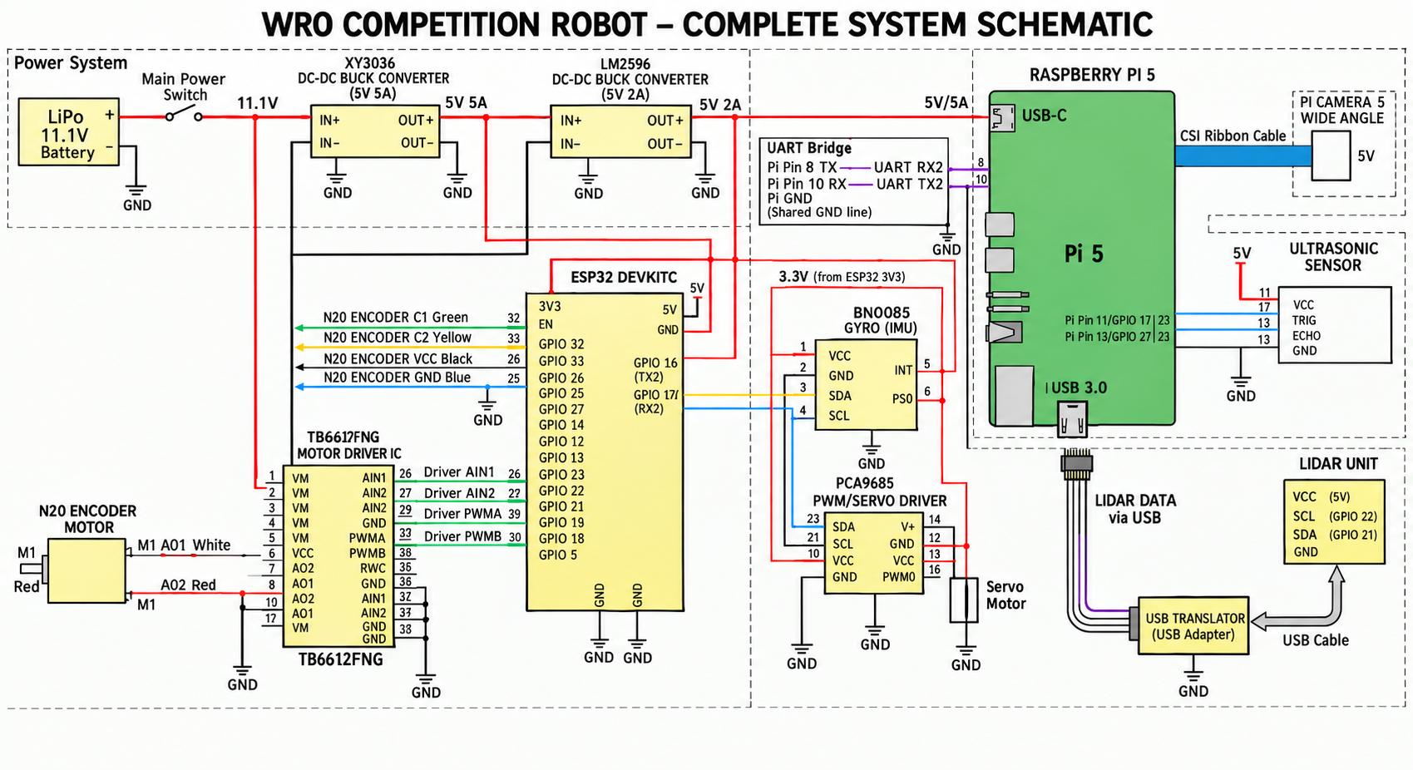
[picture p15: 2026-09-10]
elec/schematic.PNG

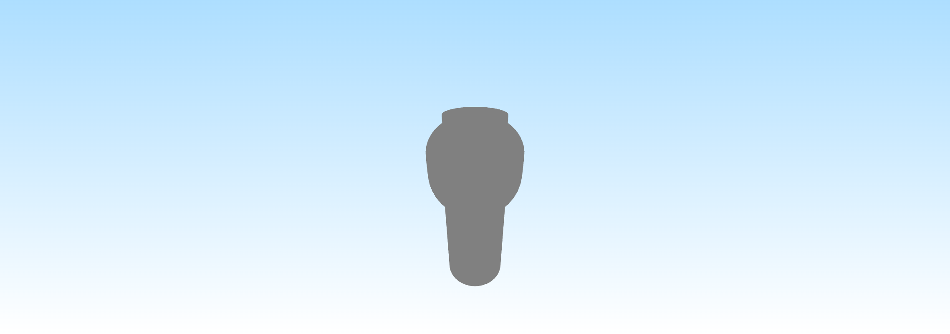
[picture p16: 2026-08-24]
mech/CAD designs/ImageToStl.com_N20 Motor Mount Bottom Plate.jpg

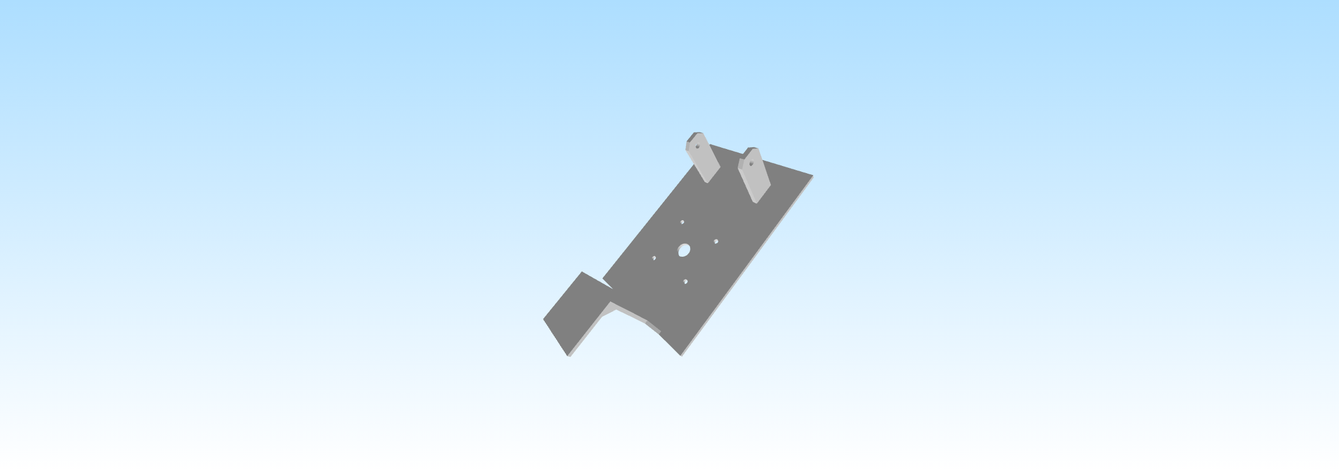
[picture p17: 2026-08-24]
mech/CAD designs/ImageToStl.com_Base Plate.jpg

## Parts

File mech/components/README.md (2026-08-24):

### Raspberry Pi 5

**Raspberry Pi 5 (Cooling Fan + SD Card):**

| **Component Image** | **Specifications** |
| --- | --- |
| Raspberry Pi 5 | 1. **Name:** Raspberry Pi 5<br><br>2. **Processor:** Quad-core 64-bit Arm Cortex-A76<br><br>3. **Storage:** MicroSD Card<br><br>4. **Cooling:** Active cooling fan<br><br>5. **Use:** Main processing and navigation |

The **Raspberry Pi 5** acts as the brain of the robot. It processes the camera and LiDAR data, runs the computer vision and navigation algorithms, makes movement decisions, and sends the resulting commands to the **ESP32**. The ESP32 then handles the low-level motor and actuator control.

**Why We Chose This Component:**

We chose the Raspberry Pi 5 as the **main computing unit** of the robot because it has enough processing power to handle computationally demanding tasks such as computer vision, LiDAR data processing, navigation, and decision-making simultaneously. Its GPIO and communication interfaces also allow it to communicate with the other hardware components. The cooling fan helps prevent overheating during continuous operation, while the SD card provides storage for the operating system, programs, and collected data.

[Buy it here](https://robu.in/product/raspberry-pi-5-model-8gb/)

---

### Raspberry Pi Camera Module 3 Wide

**Raspberry Pi Camera Module 3 Wide:**

| **Component Image** | **Specifications** |
| --- | --- |
| Raspberry Pi Camera Module 3 Wide | 1. **Name:** Raspberry Pi Camera Module 3 Wide<br><br>2. **Sensor:** Sony IMX708<br><br>3. **Field of View:** Wide-angle<br><br>4. **Interface:** CSI<br><br>5. **Use:** Image capture and computer vision |

The **Raspberry Pi Camera Module 3 Wide** provides visual input to the robot. Its wide field of view allows the robot to capture a larger portion of the track, which is useful for **track detection, object identification, and navigation**.

**Why We Chose This Component:**

We chose the Raspberry Pi Camera Module 3 Wide as the robot's primary **vision sensor** because its wide-angle field of view allows the robot to capture more of the track and surrounding environment. This is useful for identifying the track, detecting visual features, and estimating the robot's position relative to the track. Its compatibility with the Raspberry Pi also makes it suitable for real-time image processing.

[Buy it here](https://robu.in/product/raspberry-pi-camera-module-3-wide/)

---

### ESP32 Development Board

**ESP32 Development Board:**

| **Component Image** | **Specifications** |
| --- | --- |
| ESP32 Development Board | 1. **Name:** ESP32 Development Board<br><br>2. **Type:** Microcontroller<br><br>3. **Communication:** Serial communication with Raspberry Pi 5<br><br>4. **Use:** Motor and actuator control |

The **ESP32** acts as the robot's low-level motor controller. It receives movement commands from the Raspberry Pi 5, which performs the main vision, sensor processing, decision-making, and navigation. The ESP32 converts these commands into control signals for the **motor driver and steering servo**, allowing the robot to physically execute the decisions made by the Raspberry Pi.

**Why We Chose This Component:**

We chose the ESP32 as the robot's **low-level control unit** because it can respond quickly to motor and steering commands while the Raspberry Pi focuses on higher-level processing. It provides multiple GPIO and communication interfaces and can communicate with the Raspberry Pi through serial communication. This separation of responsibilities makes the overall control system more reliable and responsive.

[Buy it here](https://robu.in/product/esp32-s3-devkit-esp32-s3-wroom-1-n16r8/)

---

### YDLidar T-Mini Plus LiDAR

**YDLidar T-Mini Plus LiDAR:**

| **Component Image** | **Specifications** |
| --- | --- |
| YDLidar T-Mini Plus LiDAR | 1. **Name:** YDLidar T-Mini Plus<br><br>2. **Type:** 2D LiDAR<br><br>3. **Scan Frequency:** Up to 10 Hz<br><br>4. **Interface:** USB / Serial<br><br>5. **Use:** Distance measurement and obstacle detection |

The **YDLidar T-Mini Plus** provides 2D distance measurements around the robot. The LiDAR data is used for **obstacle detection, wall following, collision avoidance, and navigation decisions**.

**Why We Chose This Component:**

We chose the YDLidar T-Mini Plus to provide **360° distance measurements** around the robot. Unlike a camera, LiDAR provides direct distance information, which is useful for detecting obstacles and determining the available space around the robot. Its scanning capability allows our navigation system to analyse the surroundings and make decisions for obstacle avoidance and movement.

[Buy it here](https://robu.in/product/ydlidar-t-mini-plus-lidar-sensor/)

---

### PCA9685 16-Channel PWM Servo Driver

**PCA9685 16-Channel PWM Servo Driver:**

| **Component Image** | **Specifications** |
| --- | --- |
| PCA9685 16-Channel PWM Servo Driver | 1. **Name:** PCA9685 16-Channel PWM Servo Driver<br><br>2. **Channels:** 16 PWM channels<br><br>3. **Interface:** I²C<br><br>4. **I²C Address:** 0x40<br><br>5. **Use:** Servo control |

The **PCA9685** is used to generate PWM signals for controlling the robot's servo motor. It communicates with the controller through the **I²C interface**, providing precise control of the steering mechanism.

**Why We Chose This Component:**

We chose the PCA9685 to provide **precise and stable PWM control** for the steering servo. It can generate multiple PWM signals independently, allowing servo control without placing unnecessary load on the ESP32's hardware resources. Using a dedicated PWM controller also gives us consistent servo positioning, which is important for accurate steering.

[Buy it here](https://robu.in/product/16-channel-12-bit-pwmservo-driver-i2c-interface-pca9685-arduino-raspberry-pi/)

---

### TB6612FNG Dual Motor Driver

**TB6612FNG Dual Motor Driver:**

| **Component Image** | **Specifications** |
| --- | --- |
| TB6612FNG Dual Motor Driver | 1. **Name:** TB6612FNG Dual Motor Driver<br><br>2. **Type:** Dual H-Bridge motor driver<br><br>3. **Channels:** 2<br><br>4. **Control:** PWM speed control<br><br>5. **Use:** DC motor control |

The **TB6612FNG** is used to control the robot's DC motors. It allows the ESP32 to control the **direction and speed** of the motors using PWM signals.

**Why We Chose This Component:**

We chose the TB6612FNG because it can control **two DC motors independently**, including their direction and speed. Its PWM-based speed control allows us to adjust the motor output according to the robot's movement requirements. It is also compact and efficient, making it suitable for a small autonomous robot where both space and power efficiency are important.

[Buy it here](https://robu.in/product/motor-driver-tb6612fng-module-performance-ultra-small-volume-3-pi-matching-performance-ultra-l298n/)

---

### GY-87 10-DOF Multi-Sensor IMU Module

**GY-87 10-DOF Multi-Sensor IMU Module:**

| **Component Image** | **Specifications** |
| --- | --- |
| GY-87 IMU Module | 1. **Name:** GY-87 10-DOF IMU Module<br><br>2. **Sensors:** Accelerometer, gyroscope, magnetometer and barometer<br><br>3. **Interface:** I²C<br><br>4. **Degrees of Freedom:** 10-DOF<br><br>5. **Use:** Motion and orientation sensing |

The **GY-87 IMU** provides information about the robot's movement and orientation. It can be used to monitor **rotation, acceleration, and changes in orientation** during navigation.

**Why We Chose This Component:**

We chose the GY-87 to provide additional **motion and orientation information** about the robot. Its accelerometer and gyroscope can be used to detect changes in movement and orientation, while the other onboard sensors provide additional environmental and motion data. This information can complement the camera and LiDAR and can be useful for analysing the robot's movement and maintaining stable operation.

[Buy it here](https://robu.in/product/mpu6050hmc5883lbmp180-10dof-3-axis-gyro-3-axis-acceleration-3-axis-magnetic-field-air-pres/)

---

### Silicon Labs CP2102 USB-to-UART Bridge

**Silicon Labs CP2102 USB-to-UART Bridge:**

| **Component Image** | **Specifications** |
| --- | --- |
| CP2102 USB-to-UART Bridge | 1. **Name:** CP2102 USB-to-UART Bridge<br><br>2. **Type:** USB-to-UART converter<br><br>3. **Interface:** USB / UART<br><br>4. **Use:** Serial communication<br><br>5. **Application:** Programming and debugging |

The **CP2102** is used as a USB-to-UART interface for communication with the microcontroller and for **programming, debugging, and serial communication**.

**Why We Chose This Component:**

We chose the CP2102 USB-to-UART bridge to provide a reliable **serial communication interface** between a computer and the ESP32. It simplifies programming, firmware uploading, and debugging by allowing serial data to be transmitted through USB. This makes development and troubleshooting of the ESP32 control system easier.

[Buy it here](https://robu.in/product/cp2102-gmr-skyworks-silicon-labs-12mbps-transceiver-wqfn-28-ep5x5-usb-converters-rohs/)

---

### HC-SR04 Ultrasonic Sensor

**HC-SR04 Ultrasonic Sensor:**

| **Component Image** | **Specifications** |
| --- | --- |
| HC-SR04 Ultrasonic Sensor | 1. **Name:** HC-SR04 Ultrasonic Sensor<br><br>2. **Type:** Ultrasonic distance sensor<br><br>3. **Operating Voltage:** 5 V<br><br>4. **Interface:** Trigger and Echo<br><br>5. **Use:** Distance measurement |

The **HC-SR04** measures distance using ultrasonic waves. It can provide an additional proximity measurement for detecting objects near the robot.

**Why We Chose This Component:**

We chose the HC-SR04 as an additional **short-range distance sensor** to provide another source of obstacle detection. It is simple to interface with the ESP32 and can detect objects at close distances. Using it alongside the LiDAR provides an additional sensing layer that can help detect obstacles in situations where a second distance measurement is useful.

[Buy it here](https://robu.in/product/3-3-5-5v-hc-sr04-ultrasonic-sensor-4pin/)

---

### MG996 Servo Motor

**MG996 Servo Motor:**

| **Component Image** | **Specifications** |
| --- | --- |
| MG996 Servo Motor | 1. **Name:** MG996 Servo Motor<br><br>2. **Type:** Digital servo motor<br><br>3. **Control:** PWM<br><br>4. **Rotation:** Approximately 180°<br><br>5. **Use:** Steering control |

The **MG996 Servo Motor** is used to control the robot's steering mechanism. Its position is controlled using PWM signals generated through the **PCA9685 servo driver**.

**Why We Chose This Component:**

We chose the MG996 servo motor for the **steering mechanism** because it provides relatively high torque and a wide range of angular movement. Steering requires the servo to consistently hold the required position against mechanical resistance, so a higher-torque servo is appropriate for this application. Its commonly supported control interface also makes it straightforward to operate using the PCA9685.

[Buy it here](https://robu.in/product/towerpro-mg995-servo-high-speed-digital-metal-gear-servo-motor-cnc-aluminum-steering-servo-horn-arm-good-quality/)

---

### N20 200 RPM Gear Motors

**N20 200 RPM Gear Motors:**

| **Component Image** | **Specifications** |
| --- | --- |
| N20 Gear Motors | 1. **Name:** N20 DC Gear Motor<br><br>2. **Quantity:** 2<br><br>3. **Speed:** Approximately 200 RPM<br><br>4. **Type:** DC geared motor<br><br>5. **Use:** Propulsion |

Following an evaluation of different motors, we selected the **N20 200 RPM Gear Motors** for propulsion. Their compact size and geared design provide suitable torque while keeping the robot lightweight. The motors are connected to the **TB6612FNG motor driver** for speed and direction control.

**Why We Chose This Component:**

We chose the N20 200 rpm gear motors because their **compact size and geared output** provide a suitable combination of speed and torque for our robot. The gear reduction allows the motors to produce enough torque to move the robot while maintaining a manageable rotational speed. Their small form factor also makes them suitable for the limited space available within the chassis.

[Buy it here](https://robu.in/product/n20-6v-100-rpm-micro-metal-gear-box-dc-motor-2/)

---

### LiPo 3S 11.1V 2200mAh Battery

**LiPo 3S 11.1V 2200mAh Battery:**

| **Component Image** | **Specifications** |
| --- | --- |
| LiPo 3S 11.1V 2200mAh Battery | 1. **Name:** LiPo 3S Battery<br><br>2. **Nominal Voltage:** 11.1 V<br><br>3. **Capacity:** 2200 mAh<br><br>4. **Cell Count:** 3S<br><br>5. **Use:** Main power source |

The **3S LiPo battery** serves as the primary power source for the robot. Its relatively high energy density allows it to power the motors and electronic systems while maintaining a compact form factor.

**Why We Chose This Component:**

We chose a 3S 11.1V 2200 mAh LiPo battery as the main power source because it provides a good **balance between voltage, capacity, weight, and size**. The battery can supply the current required by the motors while also providing enough stored energy for the robot's electronics. Its high energy density helps keep the overall robot lightweight while still providing sufficient runtime.

[Buy it here](https://robu.in/product/orange-2200mah-3s-30c60c-lithium-polymer-battery-pack-lipo/)

---

### LM2596 Step-Down Buck Converter

**LM2596 Step-Down Buck Converter:**

| **Component Image** | **Specifications** |
| --- | --- |
| LM2596 Buck Converter | 1. **Name:** LM2596 Step-Down Converter<br><br>2. **Type:** DC-DC buck converter<br><br>3. **Input:** Higher DC voltage<br><br>4. **Output:** Adjustable lower DC voltage<br><br>5. **Use:** ESP32 power regulation |

The **LM2596 buck converter** reduces the battery voltage to a suitable regulated voltage for the **ESP32 and associated electronics**. This provides a more appropriate supply voltage while improving power efficiency.

**Why We Chose This Component:**

We chose the LM2596 buck converter to safely **reduce the battery voltage to a suitable regulated voltage** for the ESP32 and its associated electronics. Since the 3S LiPo battery provides a higher voltage than the ESP32 requires, a step-down converter is necessary. The adjustable output also allows the supply voltage to be set according to the requirements of the connected electronics.

[Buy it here](https://robu.in/product/lm2596-buck-step-power-converter-module-dc-4-040-1-3-37v-led-voltmeter/)

---

### XY-3606 DC-DC Step-Down Buck Converter

**XY-3606 DC-DC Step-Down Buck Converter:**

| **Component Image** | **Specifications** |
| --- | --- |
| XY-3606 Buck Converter | 1. **Name:** XY-3606 DC-DC Buck Converter<br><br>2. **Type:** Step-down voltage regulator<br><br>3. **Input:** Higher DC voltage<br><br>4. **Output:** Adjustable lower DC voltage<br><br>5. **Use:** Raspberry Pi power regulation |

The **XY-3606 buck converter** is used to regulate the battery voltage to a suitable level for powering the **Raspberry Pi 5**. This allows the computing system to receive a stable power supply from the main battery.

**Why We Chose This Component:**

We chose the XY-3606 buck converter to provide a **regulated power supply for the Raspberry Pi 5**. It converts the higher voltage from the LiPo battery into the voltage required by the Raspberry Pi while maintaining a stable supply. This helps prevent voltage-related instability during operation, especially when the motors are drawing significant current from the battery.

[Buy it here](https://robu.in/product/24v-12v-to-5v-5a-power-module-dc-dc-xy-3606-power-converter/)

---

### RC Car Rear Differential

**RC Car Rear Differential:**

| **Component Image** | **Specifications** |
| --- | --- |
| RC Car Rear Differential | 1. **Name:** RC Car Rear Differential<br><br>2. **Type:** Mechanical differential<br><br>3. **Use:** Power distribution to rear wheels<br><br>4. **Application:** Rear-wheel drive system |

The **RC Car Rear Differential** transfers power from the motors to the rear wheels while allowing the wheels to rotate at different speeds when turning. This improves the robot's ability to negotiate corners smoothly.

**Why We Chose This Component:**

We chose an RC car rear differential as part of the robot's **mechanical drive system** because it distributes power between the two rear wheels while allowing them to rotate at different speeds. This is particularly useful when the robot turns, as the inner and outer wheels travel different distances. The differential therefore provides smoother and more mechanically appropriate turning behaviour than directly forcing both wheels to rotate at the same speed.

[Buy it here](https://www.daddydrones.in/mjx-hypergo-16420y-metal-differential-1-14-rc-cars-14301-14303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)

---

### N20 Wheels

**N20 Wheels:**

| **Component Image** | **Specifications** |
| --- | --- |
| N20 Wheels | 1. **Name:** N20 Wheels<br><br>2. **Quantity:** 4<br><br>3. **Type:** Robot/RC wheels<br><br>4. **Compatibility:** N20 gear motors<br><br>5. **Use:** Ground contact and propulsion |

The **N20 wheels** provide the robot with traction and allow the motor torque to be transferred to the track surface. Four wheels are used to provide stable contact with the ground.

**Why We Chose This Component:**

We chose N20 wheels because they are **compact, lightweight, and mechanically compatible with the N20 gear motors** used in our drive system. Their dimensions are suitable for our chassis and provide the required ground clearance while keeping the robot compact. They also work with our rear differential setup, allowing the drive system to transfer motor power effectively to the wheels.

[Buy it here](https://robu.in/product/3pi-miniq-car-wheel-tyre-42mm-n20-dc-gear-motor-wheel/)

---

### Lazy Susan Turntable Bearings

**Lazy Susan Turntable Bearings:**

| **Component Image** | **Specifications** |
| --- | --- |
| Lazy Susan Turntable Bearing | 1. **Name:** Lazy Susan Turntable Bearing<br><br>2. **Type:** Rotational bearing<br><br>3. **Use:** Low-friction rotation<br><br>4. **Application:** Mechanical support<br><br>5. **Function:** Allows smooth rotational movement |

The **Lazy Susan turntable bearing** is used as a mechanical support component to allow smooth rotational movement while reducing friction. It contributes to the mechanical stability and movement of the robot.

**Why We Chose This Component:**

We chose Lazy Susan turntable bearings to provide **smooth rotational movement while supporting the mechanical load** of the rotating assembly. Their low-friction design reduces resistance during rotation and helps maintain consistent movement. They also provide a stable mechanical mounting point, making them useful for components that need to rotate while remaining securely supported.

[Buy it here](https://www.amazon.in/VXB-Capacity-Bearing-Turntable-Bearings/dp/B002TIKEQ6)

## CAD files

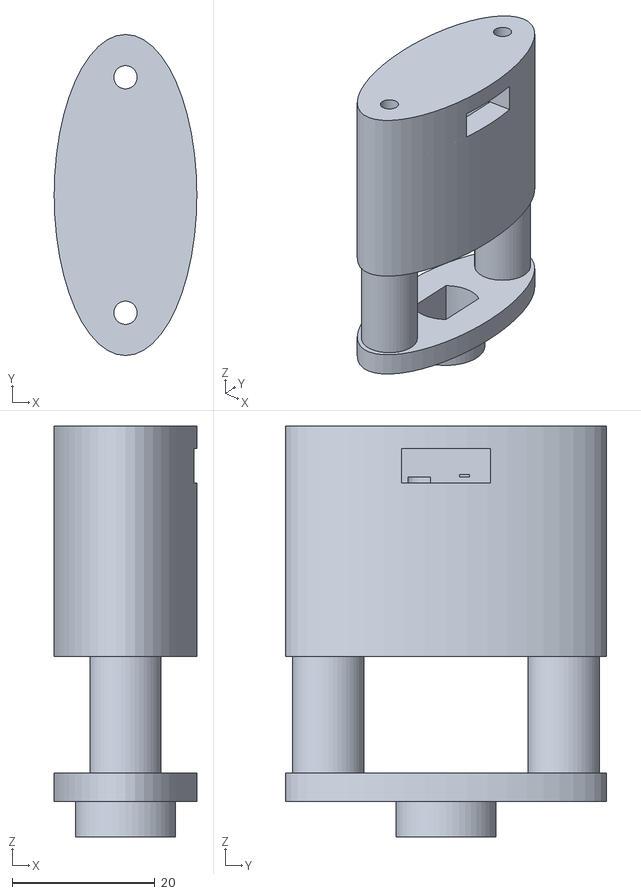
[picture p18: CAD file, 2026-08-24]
mech/CAD designs/Servo N20 Motor Mount Assembly.stl
20.0 x 45.0 x 57.6

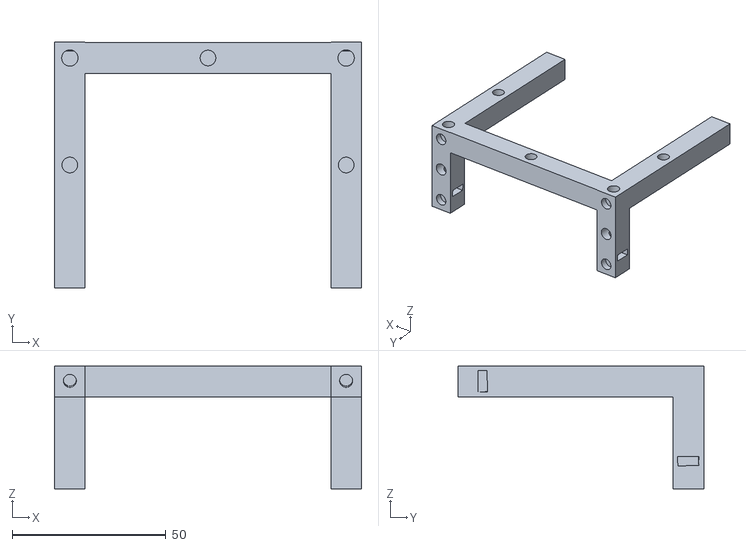
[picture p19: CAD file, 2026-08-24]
mech/CAD designs/Main Frame Back.stl
100.0 x 80.0 x 40.0

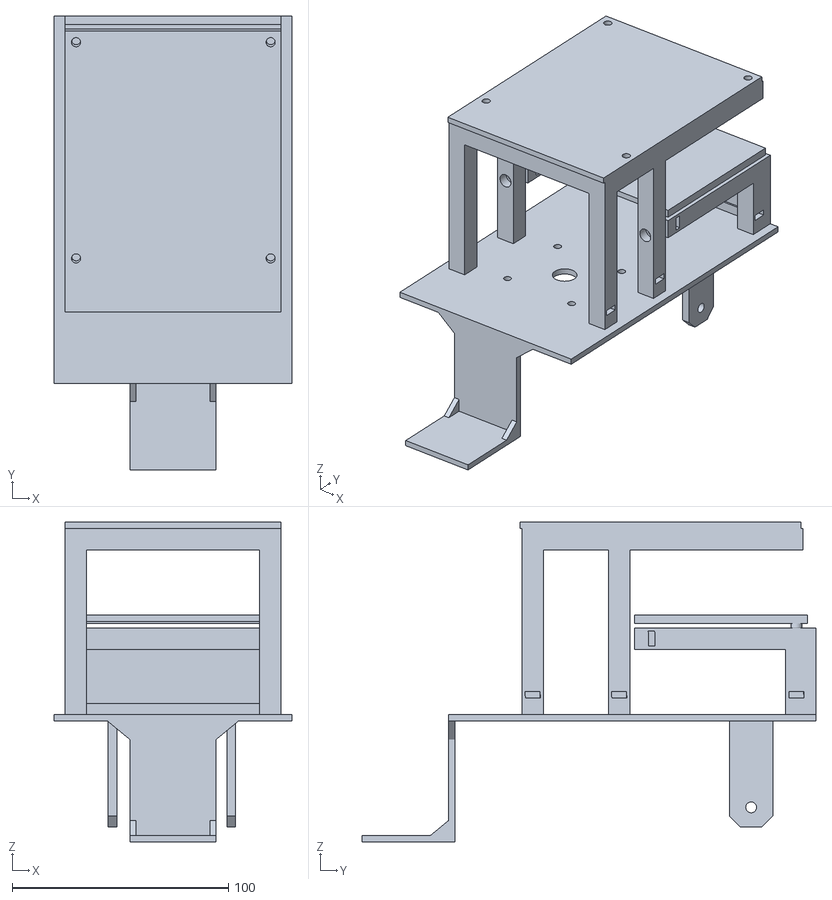
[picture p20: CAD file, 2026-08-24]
mech/CAD designs/Frame Assembly.stl
110.0 x 210.0 x 148.0

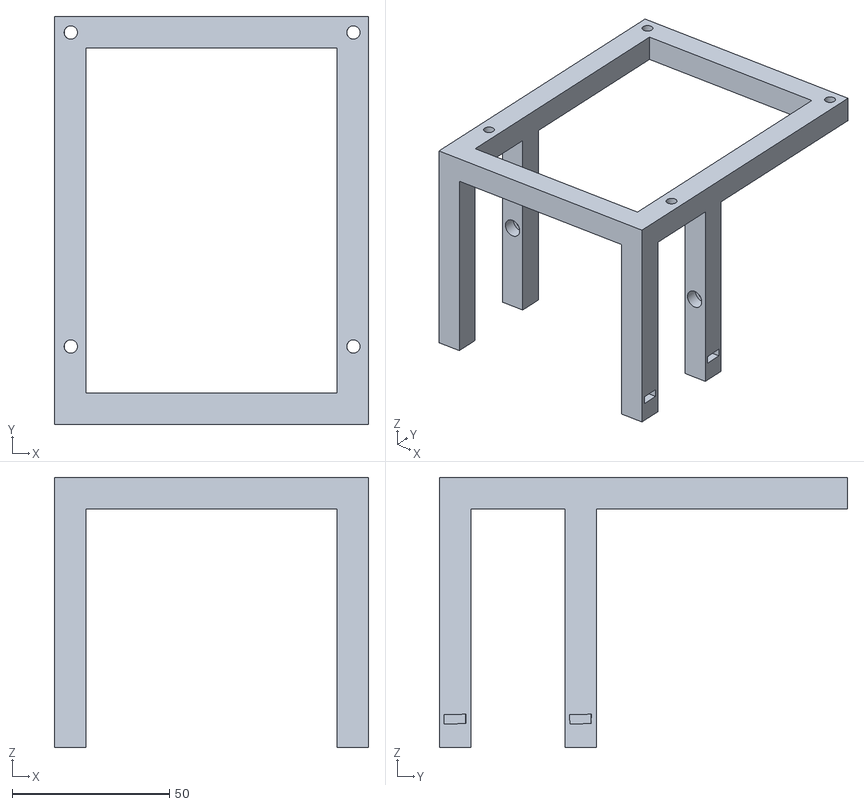
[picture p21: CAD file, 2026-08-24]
mech/CAD designs/Main Frame Front.stl
100.0 x 130.0 x 86.0

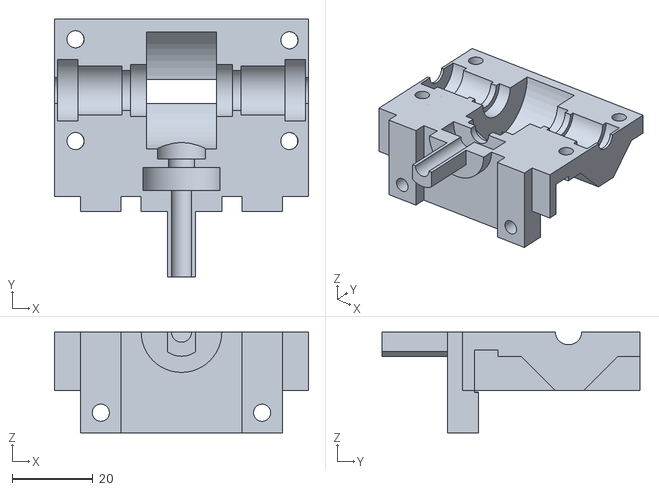
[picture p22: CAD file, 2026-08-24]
mech/CAD designs/Diffrential Part B.stl
63.0 x 63.9 x 25.0

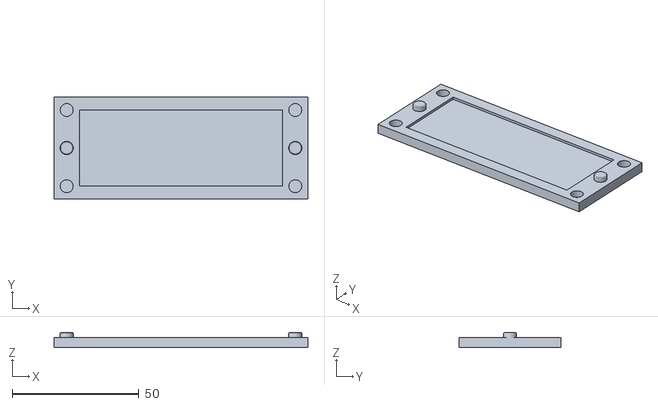
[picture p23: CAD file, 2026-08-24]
mech/CAD designs/Back Plate.stl
100.0 x 40.0 x 6.00

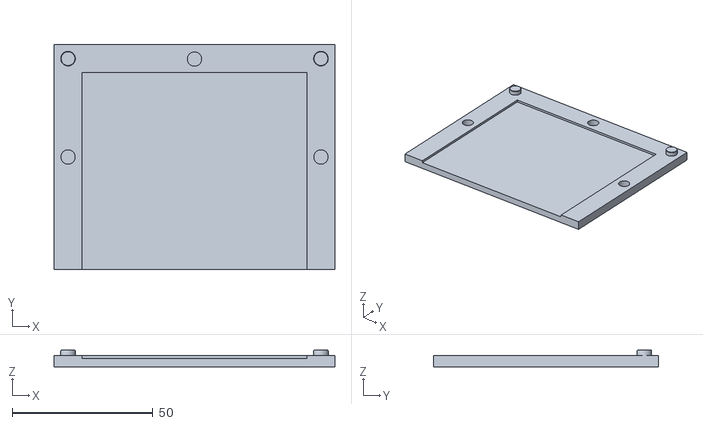
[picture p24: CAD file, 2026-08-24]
mech/CAD designs/Back Bottom Plate.stl
100.0 x 80.0 x 6.00

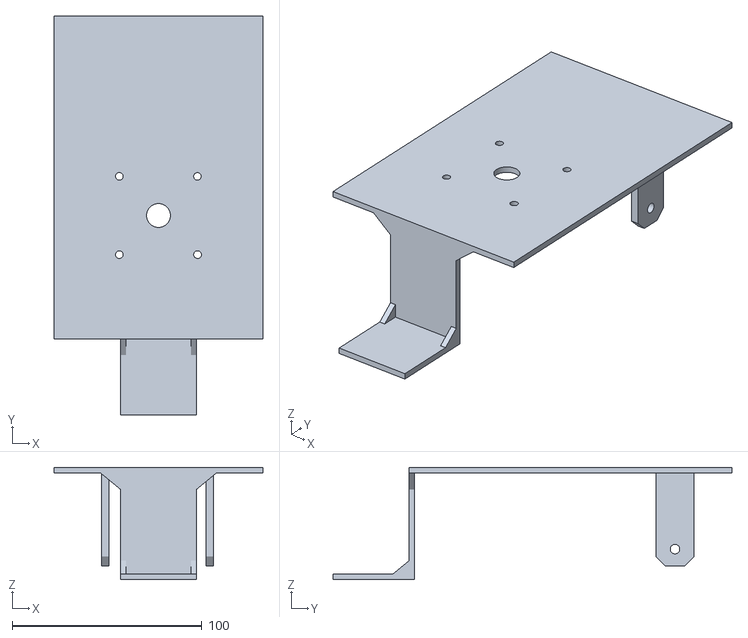
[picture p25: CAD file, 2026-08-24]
mech/CAD designs/Base Plate.stl
110.0 x 210.0 x 59.0

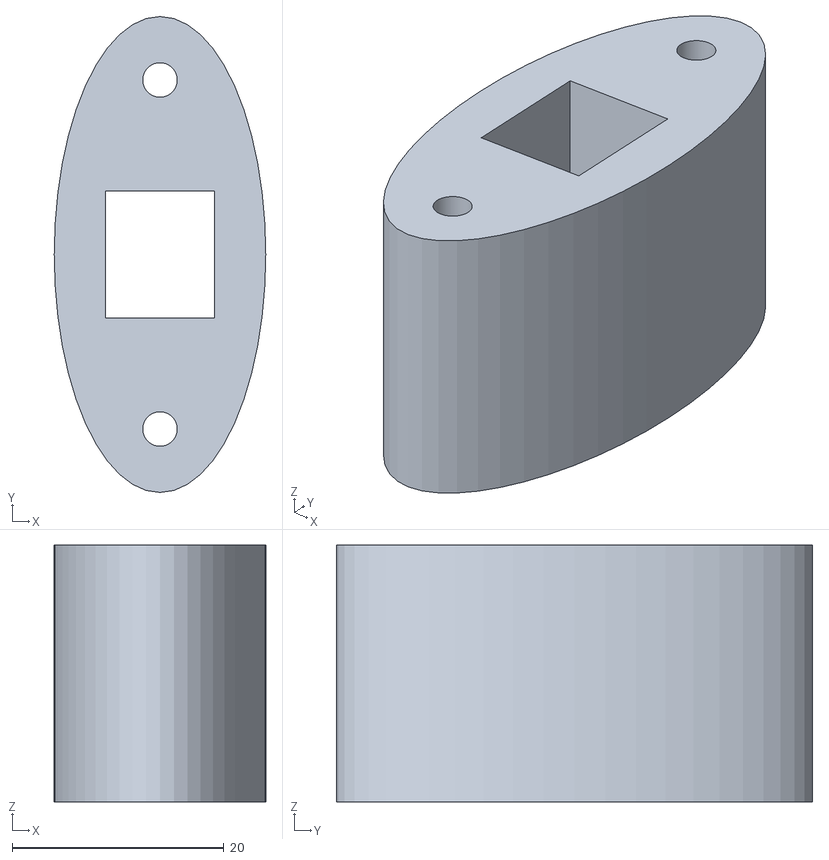
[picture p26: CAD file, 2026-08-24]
mech/CAD designs/N20 Motor Mount.stl
20.0 x 45.0 x 24.3

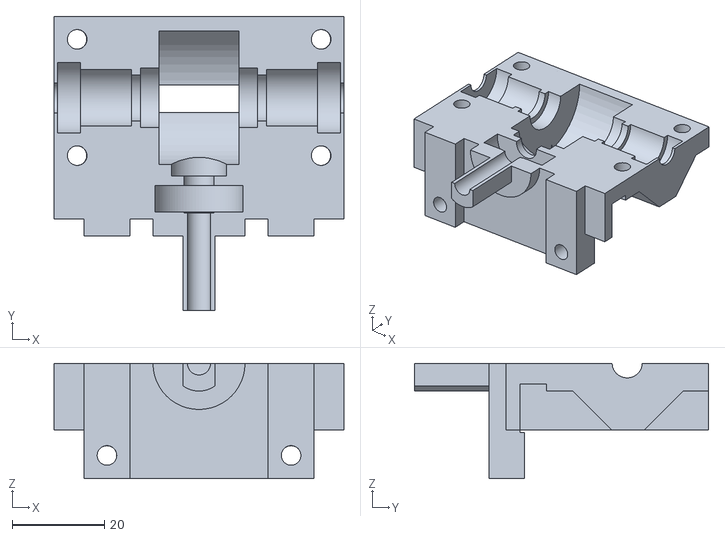
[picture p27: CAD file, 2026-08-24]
mech/CAD designs/Diffrential Part A.stl
63.0 x 63.9 x 25.0

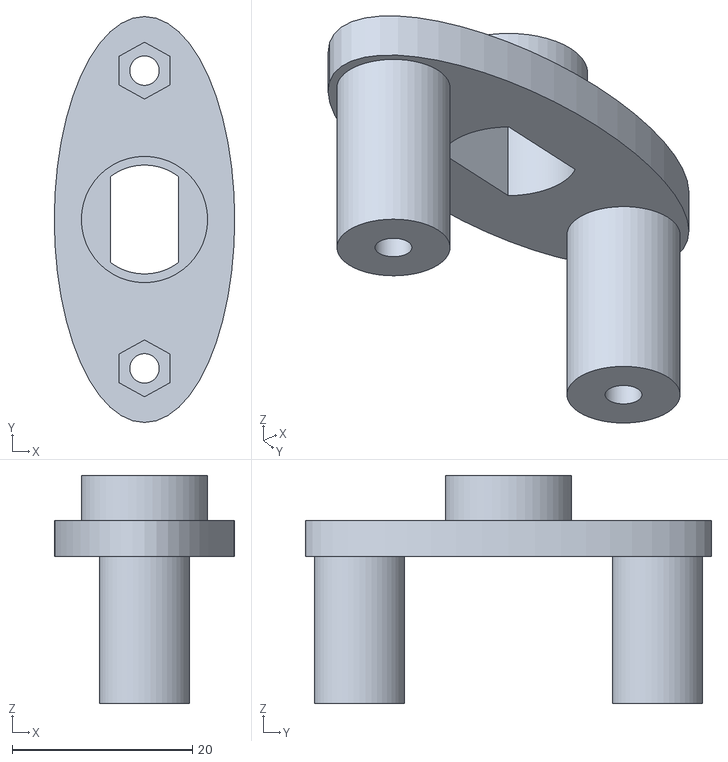
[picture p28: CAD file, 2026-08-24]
mech/CAD designs/N20 Motor Mount Bottom Plate.stl
20.0 x 45.0 x 25.3

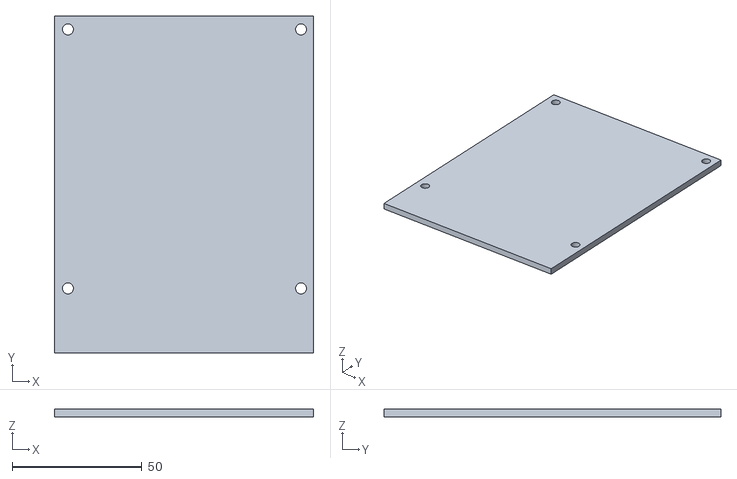
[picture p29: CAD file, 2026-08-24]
mech/CAD designs/Top Plate.stl
100.0 x 130.0 x 3.00

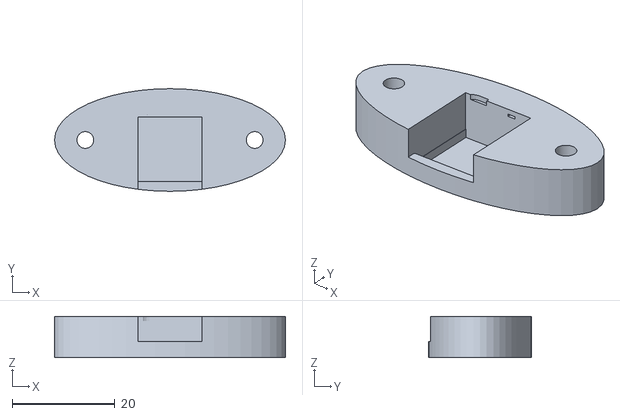
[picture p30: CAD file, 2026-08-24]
mech/CAD designs/N20 Mount Top Plate.stl
45.0 x 20.0 x 8.01

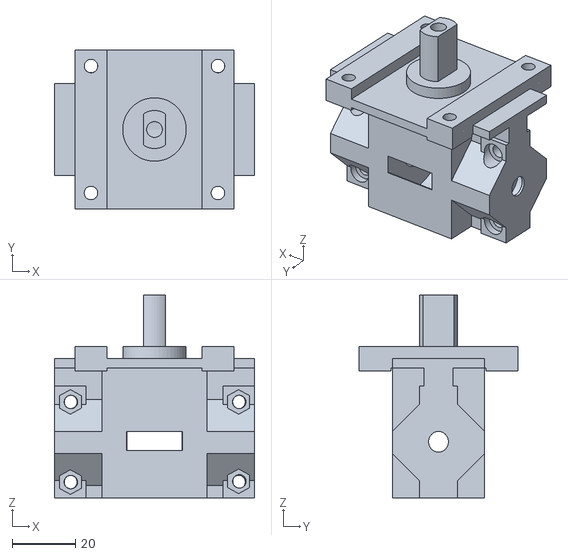
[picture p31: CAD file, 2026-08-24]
mech/CAD designs/Diffrential.stl
63.0 x 50.0 x 63.9

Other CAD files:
mech/CAD designs/lidar.stl

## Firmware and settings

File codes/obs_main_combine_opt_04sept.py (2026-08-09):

import cv2
import sys
import numpy as np
from picamera2 import Picamera2
import libcamera
from flask import Flask, render_template, Response
import threading
import time
import os
import signal

try:
    import ncnn
    NCNN_OK = True
except ImportError:
    NCNN_OK = False
    print("[WARN] ncnn not available, YOLO disabled")

try:
    import serial
except ImportError:
    serial = None

# Import custom functions
try:
    from lidar_steering4sept import LidarScanner, PIDController, calculate_steering_error
except ImportError as e:
    print(f"Error importing modules: {e}")
    sys.exit()

# --- Global Variables ---
output_frame = None
output_frame_lock = threading.Lock()

# Shared LiDAR data buffer and its lock
latest_lidar_data = {}

lidar_data_lock = threading.Lock()

# Shared buffer for the latest camera frame and its lock
latest_camera_frame = None
latest_processed_frames = {}
camera_frame_lock = threading.Lock()
camera_thread_stop_event = threading.Event()

# Shared YOLO detection results (updated by background thread)
latest_detections = []
latest_det_method = "NONE"
detection_lock = threading.Lock()


app = Flask(__name__)

# Shutdown event for graceful Ctrl+C
shutdown_event = threading.Event()

# Turn Counter Variables
turn_counter = 0
max_turn_count = 12
previous_increment_time = time.time()
START_PAUSE_DURATION = 5
DELAY_BETWEEN_TURNS = 7
OUT_PARKING_MANEUVER = False
straight_detected_time = 0.0
straight_override_duration = 1.5

# --- CONTROL CONSTANTS ---
SERVO_CENTER_ANGLE = 102
STEERING_GAIN = 0.1
ROBOT_MANEUVER_SPEED = 0.65
ROBOT_CRUISE_SPEED = 0.65
ROBOT_SPEED_MAX = 0.65


# --- CAMERA CONFIGURATION ---
CAMERA_RESOLUTION = (2304, 1296)
CAMERA_FRAMERATE = 30.0
CAMERA_BUFFER_COUNT = 4
PROCESSING_WIDTH = CAMERA_RESOLUTION[0] // 2
PROCESSING_HEIGHT = CAMERA_RESOLUTION[1] // 2
HSV_PROCESSING_WIDTH = CAMERA_RESOLUTION[0] // 3   # This will be 768
HSV_PROCESSING_HEIGHT = CAMERA_RESOLUTION[1] // 3  # This will be 432


# --- YOLO MODEL SETTINGS ---
YOLO_PARAM = '/home/pi8/wrofe2025/yolo_model/pillar_accurate/model.ncnn.param'
YOLO_BIN = '/home/pi8/wrofe2025/yolo_model/pillar_accurate/model.ncnn.bin'
YOLO_INPUT_SIZE = 640
YOLO_CONF_THRESHOLD = 0.20
YOLO_CLASSES = {0: 'red', 1: 'green'}
YOLO_PIXEL_STEERING_GAIN = 0.4
MIN_STEER_CONF = 0.25

# --- HSV FALLBACK ---
HSV_LOWER_RED1 = np.array([0, 100, 100])
HSV_UPPER_RED1 = np.array([10, 255, 255])
HSV_LOWER_RED2 = np.array([160, 100, 100])
HSV_UPPER_RED2 = np.array([180, 255, 255])
HSV_LOWER_GREEN = np.array([40, 50, 50])
HSV_UPPER_GREEN = np.array([80, 255, 255])
HSV_MIN_CONTOUR_AREA = 150
HSV_MIN_WIDTH = 25

# --- ESP32 SERIAL CONSTANTS ---
SERVO_CENTER = 95
SERVO_MIN = 77
SERVO_MAX = 127
PI_TO_ESP_PORT = "/dev/ttyAMA0"
BAUD_RATE_ESP = 115200

# --- LIDAR CONTROL CONSTANTS ---
LIDAR_TARGET_DISTANCE_MM = 500
LIDAR_SAFETY_DISTANCE_MM = 150
CLOCKWISE_WALL_FOLLOWING = True

# PID parameters (tuned for corridor centering with closest-wall distances)
LIDAR_PID_KP = 0.12
LIDAR_PID_KI = 0.002
LIDAR_PID_KD = 0.05

LIDAR_SERVO_MIN_ANGLE = 77
LIDAR_SERVO_MAX_ANGLE = 127
LIDAR_STEERING_SCALE_FACTOR = 0.25

# LiDAR side-check parameters
LIDAR_RIGHT_SIDE_CHECK_MIN_ANGLE = 40
LIDAR_RIGHT_SIDE_CHECK_MAX_ANGLE = 75
LIDAR_RIGHT_SIDE_DISTANCE_MM = 180
LIDAR_LEFT_SIDE_CHECK_MIN_ANGLE = -75
LIDAR_LEFT_SIDE_CHECK_MAX_ANGLE = -40
LIDAR_LEFT_SIDE_DISTANCE_MM = 180
LIDAR_SIDE_STEER_MAGNITUDE = 20

# --- DEBUGGING AND UI ---
STREAM_VIDEO = True
DEBUG_UI_OVERLAYS = True

# --- BEHAVIOR STATES ---
class RobotState:
    IMMINENT_COLLISION_AVOIDANCE = "IMMINENT_COLLISION_AVOIDANCE" # <-- NEW STATE
    LIDAR_SIDE_AVOIDANCE = "LIDAR_SIDE_AVOIDANCE"
    RED_AVOIDANCE = "RED_AVOIDANCE"
    GREEN_AVOIDANCE = "GREEN_AVOIDANCE"
    LIDAR_WALL_FOLLOWING = "LIDAR_WALL_FOLLOWING"
    STOP = "STOP"
    INITIALIZING = "INITIALIZING"
    FALLBACK_STRAIGHT = "FALLBACK_STRAIGHT"

current_robot_state = RobotState.INITIALIZING


def filter_blue_objects(hsv_frame):
    """Detects presence of blue using HSV masking."""
    lower_blue = np.array([80, 110, 50])
    upper_blue = np.array([130, 255, 255])
    blue_mask = cv2.inRange(hsv_frame, lower_blue, upper_blue)
    kernel = np.ones((5, 5), np.uint8)
    blue_mask = cv2.erode(blue_mask, kernel, iterations=2)
    blue_mask = cv2.dilate(blue_mask, kernel, iterations=2)
    return blue_mask

def filter_orange_objects(hsv_frame):
    """Detects presence of orange using HSV masking."""
    lower_orange = np.array([5, 100, 20])
    upper_orange = np.array([15, 255, 255])
    orange_mask = cv2.inRange(hsv_frame, lower_orange, upper_orange)
    kernel = np.ones((5, 5), np.uint8)
    orange_mask = cv2.erode(orange_mask, kernel, iterations=2)
    orange_mask = cv2.dilate(orange_mask, kernel, iterations=2)
    return orange_mask

def detect_color_binary(mask, threshold=4000):
    """Returns True if color is present above a pixel threshold."""
    return cv2.countNonZero(mask) > threshold

# ===================== ESP32 SERIAL =====================
ser = None
ESP32_OK = False

if serial is not None:
    try:
        ser = serial.Serial(PI_TO_ESP_PORT, BAUD_RATE_ESP, timeout=0.1)
        time.sleep(2)
        ESP32_OK = True
        print(f"[SERIAL] ESP32 on {PI_TO_ESP_PORT}")
    except Exception as e:
        print(f"[SERIAL] Fail: {e}")
else:
    print("[SERIAL] pyserial not available")

def cmd(angle, speed):
    if ser and ESP32_OK:
        packet = f"STR:{angle},SPD:{int(speed * 255)}\n"
        ser.write(packet.encode())
        ser.flush()

def stop_robot():
    if ser and ESP32_OK:
        ser.write(f"STR:{SERVO_CENTER},SPD:0\n".encode())
        ser.flush()

def startup_test():
    if not (ser and ESP32_OK):
        print("[STARTUP] Skipped - no serial")
        return
    print("[STARTUP] Sweeping servo...")
    for angle in [SERVO_CENTER - 20, SERVO_CENTER, SERVO_CENTER + 20, SERVO_CENTER]:
        ser.write(f"STR:{angle},SPD:0\n".encode())
        ser.flush()
        time.sleep(0.3)
    print("[STARTUP] Motor pulse...")
    cmd(SERVO_CENTER, 0.4)
    time.sleep(0.4)
    stop_robot()
    print("[STARTUP] Done")

# ===================== YOLO DETECTION =====================
yolo_net = None

def load_yolo():
    global yolo_net
    if not NCNN_OK:
        print("[YOLO] ncnn not available")
        return False
    if not os.path.exists(YOLO_PARAM):
        print(f"[YOLO] Model not found: {YOLO_PARAM}")
        return False
    print("[YOLO] Loading model...")
    yolo_net = ncnn.Net()
    yolo_net.opt.num_threads = 4
    yolo_net.load_param(YOLO_PARAM)
    yolo_net.load_model(YOLO_BIN)
    print("[YOLO] Loaded!")
    return True

def detect_yolo(img):
    if yolo_net is None:
        return None
    h, w = img.shape[:2]
    scale = YOLO_INPUT_SIZE / max(h, w)
    nw, nh = int(w * scale), int(h * scale)
    r = cv2.resize(img, (nw, nh))
    p = np.zeros((YOLO_INPUT_SIZE, YOLO_INPUT_SIZE, 3), dtype=np.uint8)
    dw = (YOLO_INPUT_SIZE - nw) // 2
    dh = (YOLO_INPUT_SIZE - nh) // 2
    p[dh:dh+nh, dw:dw+nw] = r
    mat = ncnn.Mat.from_pixels(p, ncnn.Mat.PixelType.PIXEL_BGR2RGB, YOLO_INPUT_SIZE, YOLO_INPUT_SIZE)
    mat.substract_mean_normalize([0, 0, 0], [1/255.0, 1/255.0, 1/255.0])
    ex = yolo_net.create_extractor()
    ex.set_light_mode(True)
    ex.input("in0", mat)
    _, out = ex.extract("out0")
    output = np.array(out).reshape(6, 8400).T
    class_cols = output[:, 4:]
    max_scores = np.max(class_cols, axis=1)
    mask = max_scores >= YOLO_CONF_THRESHOLD
    if not np.any(mask):
        return []
    filtered = output[mask]
    scores = max_scores[mask]
    class_ids = np.argmax(filtered[:, 4:], axis=1)
    xc = filtered[:, 0]
    yc = filtered[:, 1]
    bw = filtered[:, 2]
    bh = filtered[:, 3]
    x1 = (xc - bw / 2 - dw) / scale
    y1 = (yc - bh / 2 - dh) / scale
    x2 = (xc + bw / 2 - dw) / scale
    y2 = (yc + bh / 2 - dh) / scale
    boxes = [[float(x1[i]), float(y1[i]), float(x2[i] - x1[i]), float(y2[i] - y1[i])] for i in range(len(x1))]
    indices = cv2.dnn.NMSBoxes(boxes, scores.tolist(), YOLO_CONF_THRESHOLD, 0.45)
    dets = []
    for idx in indices.flatten() if len(indices) > 0 else []:
        i = int(idx)
        dets.append({
            'class': YOLO_CLASSES[int(class_ids[i])],
            'conf': float(scores[i]),
            'bbox': [int(x1[i]), int(y1[i]), int(x2[i]), int(y2[i])],
            'width': int(x2[i] - x1[i]),
            'cx': int((x1[i] + x2[i]) // 2)
        })
    return dets

def detect_hsv_fallback(hsv):
    red = cv2.inRange(hsv, HSV_LOWER_RED1, HSV_UPPER_RED1) + \
          cv2.inRange(hsv, HSV_LOWER_RED2, HSV_UPPER_RED2)
    green = cv2.inRange(hsv, HSV_LOWER_GREEN, HSV_UPPER_GREEN)
    dets = []
    for mask, cls in [(red, 'red'), (green, 'green')]:
        conts, _ = cv2.findContours(mask, cv2.RETR_EXTERNAL, cv2.CHAIN_APPROX_SIMPLE)
        for c in conts:
            ar = cv2.contourArea(c)
            if ar > HSV_MIN_CONTOUR_AREA:
                x, y, w, h = cv2.boundingRect(c)
                if w > HSV_MIN_WIDTH:
                    roi = mask[y:y+h, x:x+w]
                    conf = cv2.countNonZero(roi) / (w * h) if w * h > 0 else 0
                    dets.append({'class': cls, 'conf': conf, 'bbox': [x, y, x+w, y+h],
                                 'width': w, 'cx': (x + x + w) // 2})
    return dets

def detect_pillars(frame_bgr):
    """Returns (dets, method) where dets is list of detections or empty list."""
    if yolo_net is not None:
        yolo_dets = detect_yolo(frame_bgr)
        if yolo_dets is not None and len(yolo_dets) > 0:
            return yolo_dets, "YOLO"
    return [], "NONE"

def calculate_steering_angle_from_color_and_lidar(pillar_color, lidar_distance_mm, fw, pillar_cx):
    if not lidar_distance_mm or lidar_distance_mm <= 0:
        target_x = int(fw * 0.85) if pillar_color == 'red' else int(fw * 0.15)
        error = target_x - pillar_cx
        return YOLO_PIXEL_STEERING_GAIN * error
    distance_gain = max(0.2, min(2.0, 1000.0 / lidar_distance_mm))
    target_x = int(fw * 0.85) if pillar_color == 'red' else int(fw * 0.15)
    pixel_error = target_x - pillar_cx
    pixel_steering = YOLO_PIXEL_STEERING_GAIN * pixel_error
    if pillar_color == 'red':
        base_steering = 15.0 * distance_gain
    else:
        base_steering = -15.0 * distance_gain
    return base_steering + (pixel_steering * 0.5)

def compute_vision_from_detections(dets, fw, scan_data=None):
    """Returns (vision_angle, logic_label) from detection list with optional LiDAR integration."""
    reds = [d for d in dets if d['class'] == 'red']
    greens = [d for d in dets if d['class'] == 'green']

    if reds:
        largest = max(reds, key=lambda d: d['width'])
        pX = largest['cx']
        lidar_distance = None
        if scan_data:
            front_distances = [d for a, d in scan_data.items() if -5 <= a <= 5 and d > 0]
            if front_distances:
                lidar_distance = np.median(front_distances)
        vision_angle = calculate_steering_angle_from_color_and_lidar('red', lidar_distance, fw, pX)
        return vision_angle, "red_obstacle"

    if greens:
        largest = max(greens, key=lambda d: d['width'])
        pX = largest['cx']
        lidar_distance = None
        if scan_data:
            front_distances = [d for a, d in scan_data.items() if -5 <= a <= 5 and d > 0]
            if front_distances:
                lidar_distance = np.median(front_distances)
        vision_angle = calculate_steering_angle_from_color_and_lidar('green', lidar_distance, fw, pX)
        return vision_angle, "obstacle"

    return 0, "none"

def draw_detections(frame, dets):
    for d in dets:
        x1, y1, x2, y2 = d['bbox']
        clr = (0, 0, 255) if d['class'] == 'red' else (0, 255, 0)
        cv2.rectangle(frame, (x1, y1), (x2, y2), clr, 2)
        label = f"{d['class']}:{int(d['conf']*100)}%"
        cv2.putText(frame, label, (x1, y1-3), cv2.FONT_HERSHEY_SIMPLEX, 0.4, clr, 1)

# --- Helper Functions ---
def map_lidar_steering_angle(center_angle, pid_output, clockwise=True):
    adjusted_output = -1 * pid_output * LIDAR_STEERING_SCALE_FACTOR
    angle = center_angle - adjusted_output if clockwise else center_angle + adjusted_output
    return max(LIDAR_SERVO_MIN_ANGLE, min(angle, LIDAR_SERVO_MAX_ANGLE))

def check_lidar_side_alerts(scan_data):
    if not scan_data: return None
    for angle, distance in scan_data.items():
        if LIDAR_RIGHT_SIDE_CHECK_MIN_ANGLE <= angle <= LIDAR_RIGHT_SIDE_CHECK_MAX_ANGLE and 0 < distance < LIDAR_RIGHT_SIDE_DISTANCE_MM:
            return "RIGHT"
    for angle, distance in scan_data.items():
        if LIDAR_LEFT_SIDE_CHECK_MIN_ANGLE <= angle <= LIDAR_LEFT_SIDE_CHECK_MAX_ANGLE and 0 < distance < LIDAR_LEFT_SIDE_DISTANCE_MM:
            return "LEFT"
    return None

def check_front_obstacle_proximity(scan_data, distance_mm=1000):
    if not scan_data: return False
    for angle, dist in scan_data.items():
        if -2 <= angle <= 2 and 0 < dist < distance_mm:
            return True
    return False

def get_out_of_parking_lot_maneuver(scan_data, max_angle_magnitude=35, duration_sec=2, speed=ROBOT_MANEUVER_SPEED):
    """
    Analyzes LiDAR data to choose the most open path (left or right),
    sets the global wall-following direction, and executes the turn.
    """
    global CLOCKWISE_WALL_FOLLOWING
    
    start_time = time.time()
    end_time = start_time + duration_sec
    
    if not scan_data:
        print("Parking Maneuver Warning: No LiDAR data. Defaulting to RIGHT turn.")
        CLOCKWISE_WALL_FOLLOWING = True
    else:
        # Define angle ranges for checking open space
        left_distances = [dist for angle, dist in scan_data.items() if -90 <= angle <= -40 and dist > 0]
        right_distances = [dist for angle, dist in scan_data.items() if 40 <= angle <= 90 and dist > 0]
        
        avg_left = np.mean(left_distances) if left_distances else 0
        avg_right = np.mean(right_distances) if right_distances else 0
        
        print(f"Parking Maneuver Analysis: Avg Left Space={avg_left:.0f}mm, Avg Right Space={avg_right:.0f}mm")
        
        # Decide direction based on which side has more open space
        if avg_left > avg_right:
            CLOCKWISE_WALL_FOLLOWING = False # More space on left -> turn left (anti-clockwise)
            print("Decision: Turning LEFT (Anti-Clockwise). Setting wall-following mode.")
        else:
            CLOCKWISE_WALL_FOLLOWING = True # More space on right -> turn right (clockwise)
            print("Decision: Turning RIGHT (Clockwise). Setting wall-following mode.")
    
    # Execute the turn based on the decision
    direction_multiplier = 1 if CLOCKWISE_WALL_FOLLOWING else -1
    servo_angle = SERVO_CENTER_ANGLE + (direction_multiplier * max_angle_magnitude)
    print(f"Executing escape maneuver with Servo Angle: {servo_angle}")

    while time.time() < end_time:
        cmd(servo_angle, speed)
        time.sleep(0.05)

    stop_robot()
    time.sleep(0.5)

# --- NEW FUNCTION FOR IMMINENT COLLISION AVOIDANCE ---
def check_imminent_collision_and_get_escape_route(scan_data):
    """
    Checks for an imminent forward collision and determines the best escape direction.
    Trigger: Any distance < 100mm in the -10 to +10 degree range.
    Logic: Compares average free space on the left vs. right to decide which way to turn.
    Returns: "LEFT", "RIGHT", or None.
    """
    if not scan_data:
        return None

    # 1. Check for the trigger condition (imminent collision)
    is_collision_imminent = False
    for angle, distance in scan_data.items():
        if -10 <= angle <= 10 and 0 < distance < 100:
            is_collision_imminent = True
            break
    
    if not is_collision_imminent:
        return None

    # 2. If triggered, calculate escape route
    left_distances = [d for a, d in scan_data.items() if -90 <= a < 0 and d > 0]
    right_distances = [d for a, d in scan_data.items() if 0 < a <= 90 and d > 0]

    # Calculate average distance, handling cases with no valid readings
    avg_left = np.mean(left_distances) if left_distances else 0
    avg_right = np.mean(right_distances) if right_distances else 0

    # 3. Decide direction based on which side has more open space
    if avg_left > avg_right:
        return "LEFT"  # More space on the left, so turn left
    else:
        return "RIGHT" # More space on the right (or they are equal), so turn right


def check_for_straight_corridor(scan_data, min_dist_mm=1000, max_dist_mm=3500, angle_range=10):
    if not scan_data:
        return False

    left_front_distances = []
    right_front_distances = []
    angle_range_max = angle_range
    for angle, distance in scan_data.items():
        if -1*angle_range_max <= angle < 0 and distance > 0:
            left_front_distances.append(distance)
        elif 0 <= angle <= angle_range_max and distance > 0:
            right_front_distances.append(distance)

    if not left_front_distances or not right_front_distances:
        return False

    avg_left_dist = sum(left_front_distances) / len(left_front_distances)
    avg_right_dist = sum(right_front_distances) / len(right_front_distances)
    
    is_left_in_range = min_dist_mm < avg_left_dist < max_dist_mm
    is_right_in_range = min_dist_mm < avg_right_dist < max_dist_mm

    return is_left_in_range and is_right_in_range

# --- LiDAR Data Acquisition Thread ---
def lidar_acquisition_thread_func(scanner_instance):
    global latest_lidar_data, lidar_data_lock
    print("LiDAR acquisition thread started.")
    try:
        while True:
            # Check if the main thread is still alive; if not, exit.
            if not any(t.name == 'MainThread' and t.is_alive() for t in threading.enumerate()):
                break
            data = scanner_instance.get_scan_data()
            if data:
                with lidar_data_lock:
                    latest_lidar_data = data
            time.sleep(0.01)
    except Exception as e:
        print(f"LiDAR Acquisition Thread Error: {e}")
    finally:
        print("LiDAR acquisition thread stopping.")

# --- Camera Acquisition Thread ---
def camera_acquisition_thread_func(picam2_instance, stop_event, processing_size, hsv_processing_size): # <-- ADD hsv_processing_size
    global latest_processed_frames, camera_frame_lock
    print("Camera acquisition and processing thread started.")
    try:
        while not stop_event.is_set():
            # 1. Capture the single high-resolution frame
            captured_frame_rgb = picam2_instance.capture_array()

            # --- Main Processing Path ---
            # 2. Resize for main logic (e.g., lane following, display)
            processing_frame_rgb = cv2.resize(
                captured_frame_rgb,
                processing_size,
                interpolation=cv2.INTER_AREA
            )
            # 3. Convert to BGR for functions that require it
            frame_bgr = cv2.cvtColor(processing_frame_rgb, cv2.COLOR_RGB2BGR)

            # --- Color Detection Path ---
            # 4. Resize the *original* frame again to the smaller size for HSV
            hsv_source_frame = cv2.resize(
                captured_frame_rgb,
                hsv_processing_size, # <-- Use the new smaller size
                interpolation=cv2.INTER_AREA
            )
            # 5. Convert this smaller frame directly to HSV
            hsv_frame = cv2.cvtColor(hsv_source_frame, cv2.COLOR_RGB2HSV)

            # 6. Store all three prepared frames in the global dictionary
            with camera_frame_lock:
                latest_processed_frames['rgb'] = processing_frame_rgb
                latest_processed_frames['bgr'] = frame_bgr
                latest_processed_frames['hsv'] = hsv_frame # <-- ADD the new HSV frame

    except Exception as e:
        print(f"Camera Acquisition Thread Error: {e}")
    finally:
        print("Camera acquisition thread stopping.")

# --- YOLO Detection Thread ---
def detection_thread_func(stop_event):
    global latest_detections, latest_det_method, detection_lock
    print("YOLO detection thread started.")
    det_counter = 0
    while not stop_event.is_set():
        with camera_frame_lock:
            if 'bgr' not in latest_processed_frames:
                time.sleep(0.01)
                continue
            frame = latest_processed_frames['bgr'].copy()
        dets, method = detect_pillars(frame)
        with detection_lock:
            latest_detections = dets
            latest_det_method = method
        det_counter += 1
        if det_counter % 10 == 0:
            for d in dets:
                print(f"[{method}] {d['class']} conf={d['conf']:.2f} w={d['width']}")
        time.sleep(0.01)
    print("YOLO detection thread stopping.")
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

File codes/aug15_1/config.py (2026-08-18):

"""
Shared configuration for the multiprocess WRO robot control stack.

nav_process.py, lidar_process.py, and vision_process.py all import from
here so there is a single source of truth for every tunable — same role
this section played at the top of the old single-file script.
"""

# --- LIDAR / SERIAL PORTS ---
LIDAR_PORT = "/dev/ttyUSB0"
LIDAR_BAUD = 230400

PI_TO_ESP_PORT = "/dev/ttyAMA0"
BAUD_RATE_ESP = 115200

# --- LIDAR CONTROL DESIGN PARAMETERS ---
LIDAR_TARGET_DISTANCE_MM = 500
LIDAR_SAFETY_DISTANCE_MM = 200
WALL_LOSS_THRESHOLD_MM = 350.0
CLOCKWISE_WALL_FOLLOWING = True  # True -> track/follow the LEFT wall
WALL_FOLLOW_TARGET_MM = LIDAR_TARGET_DISTANCE_MM
WALL_FOLLOW_SIDE = "left" if CLOCKWISE_WALL_FOLLOWING else "right"

# --- CORNERING TUNABLES ---
CORNER_FRONT_TRIGGER_MM = 1000.0
CORNER_COOLDOWN_SEC = 5.0

# --- OUTER WALL-FOLLOW TUNABLES ---
WALL_FOLLOW_TARGET_DISTANCE_MM = 500.0
PID_OUTPUT_CLAMP = 40.0

# --- SMOOTH LIDAR SIDE-AVOIDANCE TUNABLES ---
SIDE_TRIGGER_DISTANCE_MM = 200
SIDE_STEER_MIN_MAGNITUDE = 15
SIDE_STEER_MAX_MAGNITUDE = 35

MIN_TRIGGER_POINTS = 3
TRIGGER_CONFIRM_FRAMES = 3
RELEASE_CONFIRM_FRAMES = 4

SIDE_RIGHT_ZONE_ANGLES = range(50, 90)
SIDE_LEFT_ZONE_ANGLES = range(-90, -50)

# --- FRONT SECTOR ---
FRONT_TURN_TRIGGER_MM = 200.0
FRONT_SCAN_ANGLE_DEG = 15

# --- ACTUATION CONSTANTS ---
SPEED = 255
SERVO_CENTER_ANGLE = 95
SERVO_ANGLE_LIMIT = 30
ROBOT_CRUISE_SPEED = SPEED
ROBOT_MANEUVER_SPEED = SPEED

# --- LOGGING ---
LOG_EVERY_N_LOOPS = 5
VERBOSE_LOGGING = True
PROFILING_ENABLED = True

# --- LOOP TIMING ---
NAV_LOOP_SLEEP_S = 0.005      # was time.sleep(0.02); nav is compute-only now
LIDAR_STALE_TIMEOUT_S = 0.5   # nav falls back to gyro-straight if lidar data is older than this
VISION_STALE_TIMEOUT_S = 0.5  # nav ignores vision (falls through to Tier 5) if vision data is older than this

# --- CAMERA CONFIGURATION ---
CAMERA_RESOLUTION = (2304, 1296)
LORES_RESOLUTION = (960, 540)
CAMERA_FRAMERATE = 30.0
CAMERA_BUFFER_COUNT = 4
PROCESSING_WIDTH = LORES_RESOLUTION[0]
PROCESSING_HEIGHT = LORES_RESOLUTION[1]

# --- VISION / OBSTACLE-AVOIDANCE TUNABLES ---
# Applied in vision_process.py to turn the raw steering_angle from
# process_frame_for_steering() into the final servo-adjust it publishes.
# (Ported as-is from the old single-file main loop.)
STEERING_GAIN_GREEN = 0.06
STEERING_GAIN_RED = 0.14
RED_CLEARANCE_OFFSET = 0

# --- VISION DEBUG / STREAMING ---
STREAM_VIDEO = True            # master on/off for the Flask MJPEG debug stream
DEBUG_UI_OVERLAYS = True       # draw ROI/contour/text overlays on the streamed frame
STREAM_FRAME_INTERVAL_S = 1.0 / 15.0
VISION_FLASK_PORT = 5000


class RobotState:
    INITIALIZING = "INITIALIZING"
    LIDAR_WALL_FOLLOWING = "LIDAR_WALL_FOLLOWING"
    VISION_OBSTACLE_AVOIDANCE = "VISION_OBSTACLE_AVOIDANCE"
    LIDAR_SIDE_AVOIDANCE = "LIDAR_SIDE_AVOIDANCE"
    CORNER_MANEUVER = "CORNER_MANEUVER"
    LAP_TERMINATION = "LAP_TERMINATION"
    STOP = "STOP"

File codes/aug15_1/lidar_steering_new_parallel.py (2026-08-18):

import numpy as np 
import serial
import struct
import math
import time
import ydlidar

# --- LiDAR Scanner Class (No Changes) ---
class LidarScanner:
    def __init__(self, port='/dev/ttyUSB0', baudrate=230400):
        self.port = port
        self.baudrate = baudrate
        self.laser = None
        self.scan_data = {}
        self.MIN_ANGLE = -180.0
        self.MAX_ANGLE = 180.0
        self.MIN_RANGE = 0.02
        self.MAX_RANGE = 16.0

    def connect(self):
        try:
            ydlidar.os_init()
            self.laser = ydlidar.CYdLidar()
            self.laser.setlidaropt(ydlidar.LidarPropSerialPort, self.port)
            self.laser.setlidaropt(ydlidar.LidarPropSerialBaudrate, self.baudrate)
            self.laser.setlidaropt(ydlidar.LidarPropLidarType, ydlidar.TYPE_TRIANGLE)
            self.laser.setlidaropt(ydlidar.LidarPropScanFrequency, 12.0)
            self.laser.setlidaropt(ydlidar.LidarPropSampleRate, 4)
            self.laser.setlidaropt(ydlidar.LidarPropSingleChannel, False)
            self.laser.setlidaropt(ydlidar.LidarPropMaxAngle, self.MAX_ANGLE)
            self.laser.setlidaropt(ydlidar.LidarPropMinAngle, self.MIN_ANGLE)
            self.laser.setlidaropt(ydlidar.LidarPropMaxRange, self.MAX_RANGE)
            self.laser.setlidaropt(ydlidar.LidarPropMinRange, self.MIN_RANGE)
            self.laser.setlidaropt(ydlidar.LidarPropIntenstiy, True)
            if not self.laser.initialize():
                raise IOError(f"LiDAR connection failed: {self.laser.DescribeError()}")
            if not self.laser.turnOn():
                raise IOError(f"Failed to turn on YDLIDAR: {self.laser.DescribeError()}")
            print(f"LiDAR: Connected to {self.port} at {self.baudrate} baud.")
        except Exception as e:
            raise IOError(f"LiDAR connection failed: {e}")

    def disconnect(self):
        if self.laser:
            print("LiDAR: Disconnecting...")
            self.laser.turnOff()
            self.laser.disconnecting()
            self.laser = None
            print("LiDAR: Disconnected.")

    def get_scan_data(self):
        if not self.laser: return None
        self.scan_data = {}
        scan = ydlidar.LaserScan()
        try:
            if self.laser.doProcessSimple(scan):
                for p in scan.points:
                    if self.MIN_RANGE <= p.range <= self.MAX_RANGE:
                        angle_degrees = round(math.degrees(p.angle))
                        self.scan_data[angle_degrees] = p.range * 1000
                return self.scan_data
            return None
        except Exception as e:
            print(f"LiDAR DATA ERROR: {e}")
            return None

# --- PID Controller Class (No changes) ---
class PIDController:
    def __init__(self, Kp, Ki, Kd, setpoint=0):
        self.Kp, self.Ki, self.Kd = Kp, Ki, Kd
        self.setpoint = setpoint
        self.prev_error = 0
        self.integral = 0
        self.last_time = time.time()

    def update(self, current_error):
        current_time = time.time()
        dt = current_time - self.last_time
        if dt <= 0: return self.prev_error
        P = self.Kp * current_error
        self.integral += current_error * dt
        I = self.Ki * self.integral
        derivative = (current_error - self.prev_error) / dt
        D = self.Kd * derivative
        output = P + I + D
        self.prev_error = current_error
        self.last_time = current_time
        return output

    def reset(self):
        self.prev_error = 0
        self.integral = 0
        self.last_time = time.time()

def calculate_steering_error(scan_data, target_distance_mm=750, safety_distance_mm=150, clockwise=True, verbose=False):
    """
    Calculates steering error. The sensing angles are adjusted based on whether
    the robot is performing clockwise (right-turning) or anti-clockwise
    (left-turning) wall following.

    FIX: this function is called once per main-loop iteration (30-50Hz).
    Debug prints are gated behind `verbose` — pass in the caller's own
    throttled `should_log` flag, not True/False every frame, or you'll
    reintroduce the unthrottled-print FPS drop (~3 FPS) seen previously.

    The safety-stop warning print is deliberately NOT gated by `verbose` -
    it's rare (only fires when something is genuinely too close) and you
    want it visible every time it happens regardless of log throttling.
    """
    front_angles_degrees = range(-5, 6)  # -5 to 5 degrees inclusive

    # Set the left and right wall sensing angles based on maneuver direction.
    # NOTE: these ranges genuinely differ per direction (unlike the earlier
    # version where both branches used the same range and `clockwise` had
    # no real effect).
    if clockwise:
        if verbose:
            print("LiDAR: Clockwise mode. Right Range: [45, 85], Left Range: [-85, -45]")
        right_wall_angles_degrees = range(45, 85)
        left_wall_angles_degrees = range(-85, -45)
    else:
        if verbose:
            print("LiDAR: Anti-Clockwise mode. Right Range: [30, 91], Left Range: [-90, -29]")
        right_wall_angles_degrees = range(30, 91)
        left_wall_angles_degrees = range(-90, -29)

    # --- Immediate Obstacle Detection (Safety) ---
    front_distances = [scan_data[angle] for angle in front_angles_degrees if angle in scan_data and scan_data[angle] > 0]
    for dist in front_distances:
        if dist < safety_distance_mm:
            # Always printed (not gated by verbose) - rare, safety-relevant event.
            print(f"LiDAR: WARNING! Obstacle at {dist:.0f}mm. Commanding STOP.")
            return 9999.0  # Signal for immediate stop

    # --- Wall Following Logic ---
    right_distances = [d for a, d in scan_data.items() if a in right_wall_angles_degrees and d is not None and 0 < d < 3000]
    left_distances = [d for a, d in scan_data.items() if a in left_wall_angles_degrees and d is not None and 0 < d < 3000]

    right_distances.sort(reverse=True)
    left_distances.sort(reverse=True)
    num_values = 20  # Consider the 20 furthest points to avoid noise from close objects
    top_right_distances = right_distances[:num_values]
    top_left_distances = left_distances[:num_values]

    avg_right_distance = np.mean(top_right_distances) if top_right_distances else None
    avg_left_distance = np.mean(top_left_distances) if top_left_distances else None

    if verbose and (avg_right_distance is not None or avg_left_distance is not None):
        print(f"LiDAR: Avg Right: {avg_right_distance or 'N/A'}, Avg Left: {avg_left_distance or 'N/A'}")
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

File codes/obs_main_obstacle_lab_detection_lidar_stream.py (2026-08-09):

import cv2
import sys
import numpy as np
from picamera2 import Picamera2
import libcamera
from flask import Flask, render_template, Response, request, jsonify
import threading
import time
import os
import json
import signal

try:
    import serial
except ImportError:
    serial = None

# Import custom functions
try:
    from lidar_steering4sept import LidarScanner, PIDController, calculate_steering_error
except ImportError as e:
    print(f"Error importing modules: {e}")
    sys.exit()

# --- Global Shutdown Event ---
shutdown_event = threading.Event()

# --- Global Buffers & Locks ---
lidar_data_lock = threading.Lock()
latest_lidar_data = {}

camera_frame_lock = threading.Lock()
latest_processed_frames = {}

# Dictionary to hold the final rendered streams for the Flask web UI
display_lock = threading.Lock()
display_frames = {
    "original": None,
    "lidar": None,
    "track": None,
    "red": None,
    "green": None,
    "orange": None,
    "blue": None,
    "white": None
}

# Real-time telemetry dictionary for dashboard UI text blocks
telemetry_lock = threading.Lock()
lidar_telemetry = {"front": "--", "left": "--", "right": "--"}

# --- POWER / CPU BUDGET ---
CONTROL_LOOP_MAX_HZ = 30.0      
STARTUP_STAGE_DELAY_SEC = 2.0   

# --- Turn Counter & State Variables ---
turn_counter = 0
max_line_crossings = 12
OUT_PARKING_MANEUVER = False
START_PAUSE_DURATION = 5
DELAY_BETWEEN_TURNS = 7

# --- CONTROL CONSTANTS ---
SERVO_CENTER_ANGLE = 102
STEERING_GAIN = 0.1
ROBOT_MANEUVER_SPEED = 0.75
ROBOT_CRUISE_SPEED = 0.8
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

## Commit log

2026-08-09 Add current WRO robotics code
    Added the current working versions of all WRO robotics code, including navigation, camera detection, LiDAR, and supporting scripts. These are ongoing development versions and will be updated as the p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
2026-08-15 Revise components and add mobility management details
    Updated component list and added details about robot mobility and motor control.
2026-08-15 Enhance README with power and navigation details
    Added detailed sections on power management, hardware architecture, obstacle management, and navigation algorithms.
2026-08-15 Enhance README with detailed hardware architecture
    Clarified the roles of Raspberry Pi 5 and ESP32 in the robot's architecture. Expanded on the functionalities of the GY-87 IMU and YDLidar T-Mini Plus for navigation and obstacle avoidance.
2026-08-15 Enhance README with sensor details and image processing
    Updated the README to provide detailed descriptions of the GY-87 IMU and the image processing pipeline for obstacle detection and navigation.
2026-08-18 Add image for Lazy Susan Turntable Bearings
2026-08-22 Revise README for mechanical design updates
    Updated the README to reflect changes in the mechanical design approach, including modifications to the differential gear orientation and component choices. Added sections on steering system, mobilit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
2026-08-22 added explanation for the differential gear
2026-08-23 Revise README for component specifications and clarity
    Updated README to include detailed specifications and descriptions for Raspberry Pi 5, Camera Module, ESP32, and other components. Removed outdated sections and improved formatting for clarity.
2026-08-23 Revise Raspberry Pi 5 and ESP32 specs in README
    Updated specifications and descriptions for Raspberry Pi 5 and ESP32 Development Board in README.
2026-08-23 Enhance README with component details and links
    Updated component descriptions and added links for various robot parts including Raspberry Pi 5, ESP32, and sensors.
2026-08-23 added a folder for CAD files
2026-08-23 adding .stl files
    [lidar.stl]
2026-08-23 Add building instructions to README
    Added building instructions including parts list and 3D printing details.
2026-08-23 Enhance README with additional resources and instructions
    Added links for STL files, schematics, electrical drawings, and sensor setup instructions.
2026-08-24 Enhance README with motor control and architecture details
    Added images and detailed descriptions for motor control and hardware architecture sections.
2026-08-24 Fix image tags in README for motor control and architecture
    Updated image tags in the README for better rendering.
2026-08-24 added 3D CAD Designs of the robot
    [Back Bottom Plate.stl, Back Plate.stl, Base Plate.stl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]
2026-08-24 added jpeg files for all CAD designs
2026-08-24 Enhance README with robot specs and component links
    Added details about robot dimensions, custom mounts, and differential gear. Included links to CAD designs and explanations for component choices.
2026-08-25 Update README to remove prototype sections
    Removed sections on structural prototypes and final 3D-printed structure from the README.
2026-09-10 added schematic diagrams
2026-09-10 changed schematic drawing
2026-09-10 Revise README for WRO Competition Robot documentation
    Updated the README to reflect the complete system documentation for the WRO competition robot, including detailed sections on the main power system, Raspberry Pi, ESP32 controller, and overall archit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
2026-09-13 Add Mermaid diagram for Obstacle Round Logic
    Replaced the Obstacle Round Logic image with a detailed Mermaid diagram illustrating the logic flow for various sections of the system.
2026-09-13 Add drivetrain torque calculation documentation
    Document the calculations for drivetrain torque and driving force of the WRO robot, including parameters, formulas, and results.
2026-09-13 Add WRO Drivetrain Torque Calculator HTML
    This file implements an interactive torque calculator for WRO drivetrain, allowing users to input parameters and visualize results.
2026-09-13 Add interactive torque calculator section
    Added an interactive torque calculator section with details on its functionality and a link to access it.
2026-09-15 Fix link to Interactive Torque Calculator
    Updated the link to the Interactive Torque Calculator with the correct username.
2026-09-15 Fix link to Interactive Torque Calculator
    Updated the link to the Interactive Torque Calculator in the documentation.
2026-09-15 Update link to drivetrain torque calculation documentation
2026-09-17 Fix formatting in Power & Sense Management link
2026-09-17 Fix typo in Power and Sense Management section
2026-09-17 Revise README for clarity and section updates
    Updated section headers and simplified LiDAR positioning explanation.
2026-09-19 Update flowchart for corner logic in README
2026-09-19 Revise flowchart for Corner Logic Obstacle Round
    Updated the flowchart in the README to clarify the lap and section descriptions for the Corner Logic Obstacle Round.
2026-09-19 Update links to schematics and electrical drawings
2026-09-22 Revise motor details in README
    Updated motor references and specifications in the README.
